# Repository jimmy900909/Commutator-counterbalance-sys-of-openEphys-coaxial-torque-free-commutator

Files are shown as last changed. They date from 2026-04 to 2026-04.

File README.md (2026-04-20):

This is a wireless counterbalance system that can adjust the length of the cable automatically for OpenEphys commutator while conducting freely moving animal experiment

#closed-loop Automatic Counterbalance animal experiment system

#tension-free and biting-prevention for cable in the freely moving animal experiment

The toggling and dragging can seriously cause the artifacts to signal when doing a cable-connected behavior experiment on an awake and freely-moving animal. The automatic rotation commutator is widely used in labs and commercialized, however, to adjust the length of the cable is always depends on manual holding or passive counterbalance sys. As the hanged part would be bited by animal and the tension can constraint the movement, a active counterbalance system is needed for such animal experiment.

This system consist of two part, openEphys(OE) commutator for torque-free compensation, and conterbalance system for tension control. 

Rotation commutator recieve the orientation data of the markers(rigid body) from Motive and send it to the commutator through Natnet SDK(https://optitrack.com/software/natnet-sdk)
The python code ui.py send the command that rotate the same degree as the target does to the commutator.

The counterbalance system detect the tension of the thread connected to the data acquisition cable, retract or release the thread to control the tension in a threshold.  

Following is the Assembly instructions of the mechanical structure. The CAD files are under counterbalance/mechanical design 


User guide
1.connect the OE commutator to the PC through the serial port(USB)
2.Open motive, select the reigid body and enable streaming
3.Run ui.py in the under the Natnet python client
4.Pause the rotation compensation first 
5.Set up the the counterbalance system by plug in the power, at the set time leave the thread from the loadcell to start from 0 weight.
6.start the rotation commutator

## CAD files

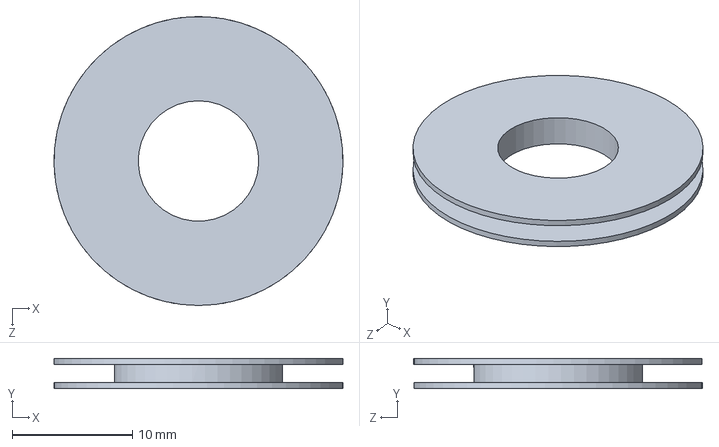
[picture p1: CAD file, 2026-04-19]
counterbalance/Mechanical design/pulley_fixed.SLDPRT
24.0 x 2.50 x 24.0 mm

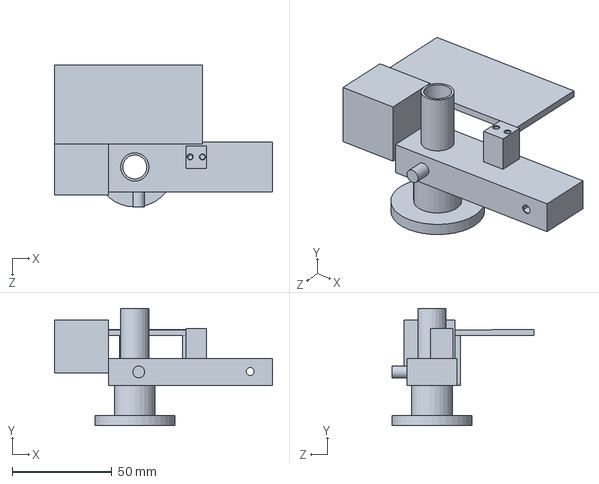
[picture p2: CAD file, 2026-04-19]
counterbalance/Mechanical design/Holder_OE.SLDPRT
109.1 x 58.7 x 71.0 mm

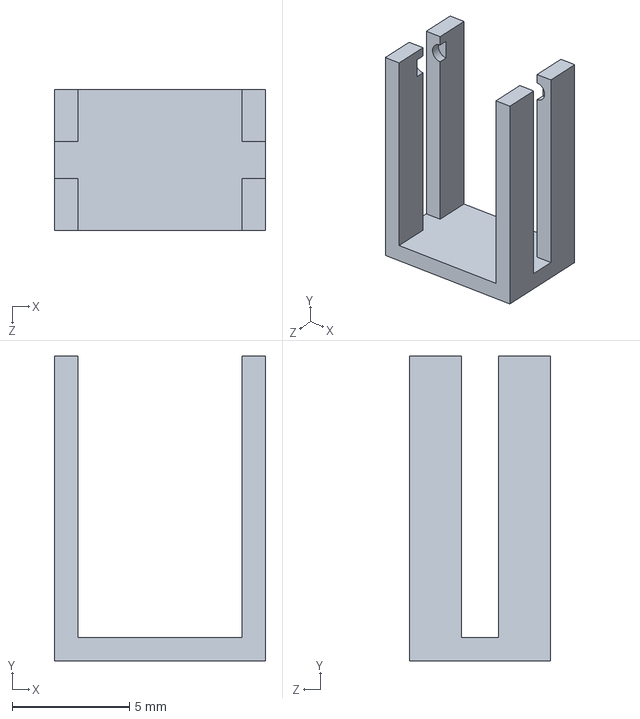
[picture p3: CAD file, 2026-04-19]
counterbalance/Mechanical design/loadcell_holder.SLDPRT
9.00 x 13.0 x 6.00 mm

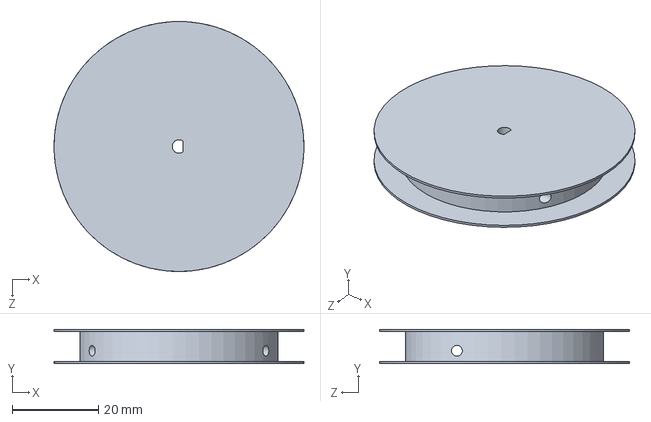
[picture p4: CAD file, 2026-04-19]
counterbalance/Mechanical design/pulley_motor.SLDPRT
58.0 x 8.00 x 58.0 mm

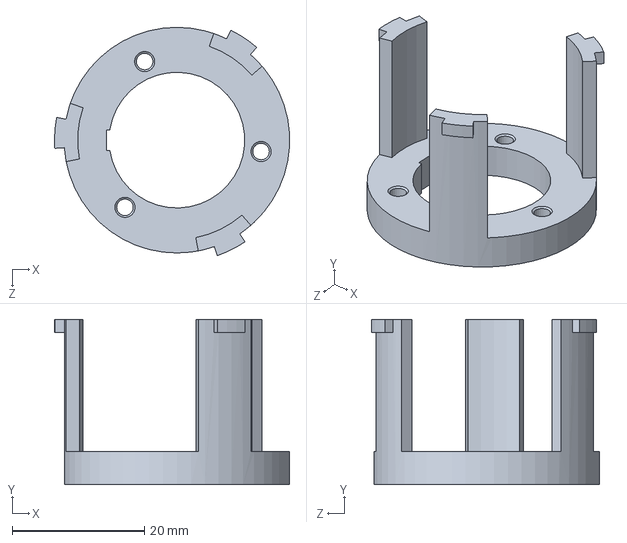
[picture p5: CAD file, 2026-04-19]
counterbalance/Mechanical design/adaptor_OE.SLDPRT
35.5 x 25.0 x 34.5 mm

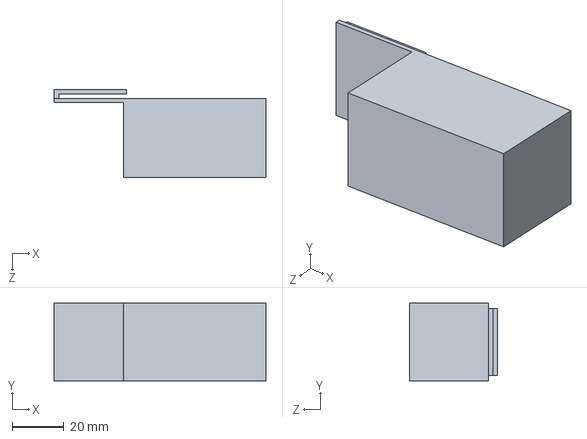
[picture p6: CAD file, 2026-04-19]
counterbalance/Mechanical design/powerbank_holder.SLDPRT
82.0 x 30.0 x 34.0 mm

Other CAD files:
counterbalance/Mechanical design/adaptor_OE.STL
counterbalance/Mechanical design/powerbank_holder.STL
counterbalance/Mechanical design/pulley_fixed.STL
counterbalance/Mechanical design/pulley_motor.STL

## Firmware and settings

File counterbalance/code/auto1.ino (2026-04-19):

#include "HX711.h"
// ---------------- Pins ----------------
// HX711
#define DOUT 4  
#define CLK  5  

// DRV8833(MOTOR driver)
#define AIN1 6
#define AIN2 9
// Encoder pins
#define ENCODER_A 2
#define ENCODER_B 3

// ---------------- HX711 ----------------
HX711 scale;
float calibration_factor = 7180;  // g
const float HX_RATE_HZ = 80.0f;   // sampling rate after soldering modication
unsigned long last_hx_ms = 0;
bool hx_updated = false;
bool have_prev_T = false;

// ---------------- Encoder → v_line ----------------
const float COUNTS_PER_METER = 11357.0f;
volatile long encoderCount = 0;
long lastCount = 0;
unsigned long lastVtMs = 0;
float v_line = 0.0f;         
float leash_len_m = 0.0f;

// ---------------- Motor / PWM ----------------
const int remotorSpeed = 65;   // retract PWM (upper bound)
int pwm_state = 0;
const int PWM_STEP_OUT = 80;   
const int PWM_STEP_IN  = 30;   
// retracting PWM
const int   BASE_RETRACT_PWM     = 35;     
const int   MAX_RETRACT_PWM      = 60;     
const int   MIN_RETRACT_PWM      = 40;     
const float KP_RETRACT_PWM_PER_G = 3.0f;   

// loosening PWM
const int   BASE_PAYOUT_PWM   = 50;
const int   MAX_PAYOUT_PWM    = 110; //upperlimit of payout
const float KP_PWM_PER_G      = 4.0f;

// ---------------- Burst（instantpayout for strong drag） ----------------
const int BURST_PWM = 100;                     
const unsigned long BURST_MS = 50;            
unsigned long burst_until_ms = 0;

// ---------------- Landing impact give-way ----------------
const float IMPACT_DTDT_GPS = 90.0f;            
const float IMPACT_NEAR_UPPER_G = 0.8f;         
const unsigned long IMPACT_COAST_MS = 120;      
const int IMPACT_PAYOUT_PWM = 70;               
unsigned long impact_until_ms = 0;              

// No instanst retracting after burst
const unsigned long POST_BURST_NO_RETRACT_MS = 600;     
unsigned long no_retract_until_ms = 0;

// ---------------- Smoothen tension for EMA filter----------------
float T_fast_g = 0.0f;                
float T_slow_g = 0.0f;                
const float T_ALPHA_FAST = 0.5f;      
const float T_ALPHA_SLOW = 0.3f;

// ---------------- threshold ----------------
float lower_limit = 22.3f;
float upper_limit = 37.5f;

float V_OUT_MIN = 0.004f;             
float T_MARGIN_G = 0.7f;
unsigned long ALLOW_PAYOUT_CONFIRM_MS = 5;  
bool allow_payout_latch = false;
unsigned long allow_payout_since_ms = 0;

// 鎖軸快速通道
const float V_EPS_LOCKED   = 0.003f;
const float T_LOCK_MARGING = 3.0f;
const float DTDT_LOCK_GPS  = 55.0f;
const unsigned long LOCK_CONFIRM_MS = 12;
bool locked_latch = false;
unsigned long locked_since_ms = 0;

// ---- dT/dt ----
float dTdt_raw = 0.0f;
float dTdt_gps = 0.0f;
float T_prev_for_dt = 0.0f;
const float DTDTA = 0.25f;

// Active-Coast when the tension near the upper limit
const int ASSIST_PWM = 80;               

// ---------------- Anti-chatter / Grace ----------------
bool inRetract = false;
unsigned long retract_start_ms;
long          retract_start_cnt;

const unsigned long MIN_RETRACT_MS  = 50;
const long          MIN_RETRACT_CNT = 10;

const unsigned long LOOSEN_GRACE_MS = 900;
unsigned long loosen_grace_until_ms = 0;

const float LOWER_HYST_G = 0.8f;

// ---------------- Loop time ----------------
const unsigned long LOOP_MS = 1;
unsigned long last_loop_ms = 0;

// ---------------- helpers ----------------
inline void motorCoast() {
  digitalWrite(AIN1, LOW);
  digitalWrite(AIN2, LOW);
}

void driveMotor(int pwmSigned) {
  if (pwmSigned == 0) { motorCoast(); return; }
  if (pwmSigned > 0) {           
    int pwm = constrain(pwmSigned, 0, 255);
    digitalWrite(AIN1, LOW);
    analogWrite(AIN2, pwm);
  } else {                       
    int pwm = constrain(-pwmSigned, 0, 255);
    analogWrite(AIN1, pwm);
    digitalWrite(AIN2, LOW);
  }
}

int slewPWM(int target) {
  if (target == pwm_state) return pwm_state;
  if ((target > 0 && pwm_state >= 0) || (target < 0 && pwm_state <= 0)) {
    int step = (target > 0) ? PWM_STEP_IN : PWM_STEP_OUT;
    if (target > pwm_state) pwm_state = min(pwm_state + step, target);
    else                    pwm_state = max(pwm_state - step, target);
  } else {
    int step = (pwm_state > 0) ? PWM_STEP_IN : PWM_STEP_OUT;
    if (pwm_state > 0) pwm_state = max(0, pwm_state - step);
    else               pwm_state = min(0, pwm_state + step);
  }
  return pwm_state;
}

int map_constrain_float(float x, float in_min, float in_max, int out_min, int out_max) {
  if (in_max - in_min == 0) return out_min;
  float t = (x - in_min) / (in_max - in_min);
  if (t < 0) t = 0; if (t > 1) t = 1;
  float y = out_min + t * (out_max - out_min);
  return (int)y;
}

int applyDeadzone(int pwmSigned) {
  const int DEADZONE = 70;   
  if (pwmSigned == 0) return 0;
  if (pwmSigned > 0) {
    return max(pwmSigned, DEADZONE);
  } else {
    return min(pwmSigned, -DEADZONE);
  }
}

// ---------------- setup ----------------
void setup() {
  Serial.begin(9600);
  delay(300);

  scale.begin(DOUT, CLK);
  delay(1500);
  if (!scale.is_ready()) { Serial.println("HX711 not found."); while (1); }
  scale.set_scale(calibration_factor);
  scale.tare();

  pinMode(AIN1, OUTPUT);
  pinMode(AIN2, OUTPUT);
  motorCoast();

  pinMode(ENCODER_A, INPUT_PULLUP);
  pinMode(ENCODER_B, INPUT_PULLUP);
  attachInterrupt(digitalPinToInterrupt(ENCODER_A), encoderISR, CHANGE);

  lastVtMs = millis();
  last_loop_ms = millis();
  last_hx_ms = millis();
  T_prev_for_dt = 0.0f;

  Serial.println("Ready ver5.instant-payout (no SD log).");
}

// ---------------- loop ----------------
void loop() {
  if (millis() - last_loop_ms < LOOP_MS) return;
  last_loop_ms = millis();

  // ---- 張力 ----
  hx_updated = false;
  float raw = 0.0f;
  if (scale.is_ready()) {
    raw = scale.get_units(1);
    T_fast_g = T_fast_g + T_ALPHA_FAST * (raw - T_fast_g);
    T_slow_g = T_slow_g + T_ALPHA_SLOW * (raw - T_slow_g);
    hx_updated = true;
  }
  float T_fast = T_fast_g;
  float T_slow = T_slow_g;

  unsigned long now = millis();
  unsigned long dt_ms = now - lastVtMs; if (dt_ms == 0) dt_ms = 1;
  lastVtMs = now;

  long cnt; noInterrupts(); cnt = encoderCount; interrupts();
  long dcount = cnt - lastCount; lastCount = cnt;

  float dt = dt_ms * 1e-3f;
  v_line = (COUNTS_PER_METER > 1e-6f) ? ((float)dcount / COUNTS_PER_METER) / dt : 0.0f;
  leash_len_m += v_line * dt;

  if (hx_updated) {
    float dtT_s = max(0.001f, (now - last_hx_ms) * 1e-3f);
    if (!have_prev_T) { dTdt_raw = 0.0f; have_prev_T = true; }
    else               dTdt_raw = (T_fast - T_prev_for_dt) / dtT_s;
    T_prev_for_dt = T_fast;
    last_hx_ms = now;
  }
  dTdt_gps = DTDTA * dTdt_raw + (1.0f - DTDTA) * dTdt_gps;

  // ---- instant payout decision ----
  bool sudden_pull = ((raw > upper_limit + 15.0f) || (T_fast > upper_limit + 15.0f)) && (dTdt_gps > 70.0f);
  bool not_retracting = (v_line <= 0.0f);
  bool instant_payout = sudden_pull && not_retracting;

  if (instant_payout) {
    unsigned long new_until = now + BURST_MS;
    if (new_until > burst_until_ms) burst_until_ms = new_until;
    loosen_grace_until_ms = max(loosen_grace_until_ms, now + LOOSEN_GRACE_MS);
    no_retract_until_ms   = max(no_retract_until_ms,   now + POST_BURST_NO_RETRACT_MS);
    inRetract = false;
    Serial.println("00000");
    allow_payout_latch = true;
    allow_payout_since_ms = now;
  }

  if (now < burst_until_ms) {
    int steppedPWM = slewPWM(-BURST_PWM);
    steppedPWM = applyDeadzone(steppedPWM);
    driveMotor(steppedPWM);
    return;
  }

  bool impact_detect = inRetract && ((dTdt_gps > IMPACT_DTDT_GPS) || (T_fast > upper_limit - IMPACT_NEAR_UPPER_G));
  if (impact_detect) {
    unsigned long new_until = now + IMPACT_COAST_MS;
    if (new_until > impact_until_ms) impact_until_ms = new_until;
  }
  if (now < impact_until_ms) {
    int targetPWM = 0;
    if (T_fast > upper_limit - 0.3f) {
      targetPWM = -IMPACT_PAYOUT_PWM; 
    }
    int steppedPWM = slewPWM(targetPWM);
    steppedPWM = applyDeadzone(steppedPWM);
    driveMotor(steppedPWM);
    inRetract = false;
    return;
  }

  bool line_out = (v_line < -V_OUT_MIN);
  bool high_T   = (T_fast > (upper_limit + T_MARGIN_G));
  if (high_T) {
    if (!allow_payout_latch) { allow_payout_latch = true; allow_payout_since_ms = now; }
  } else {
    allow_payout_latch = false;
  }
  bool allow_payout_dir = allow_payout_latch && (now - allow_payout_since_ms >= ALLOW_PAYOUT_CONFIRM_MS);

  bool spool_static = (fabs(v_line) < 0.003f);
  bool locked_trig  = spool_static && (T_fast > upper_limit + T_LOCK_MARGING) && (dTdt_gps > DTDT_LOCK_GPS);
  if (locked_trig) {
    if (!locked_latch) { locked_latch = true; locked_since_ms = now; }
  } else {
    locked_latch = false;
  }
  bool allow_payout_locked = locked_latch && (now - locked_since_ms >= LOCK_CONFIRM_MS);
  bool allow_payout = allow_payout_dir || allow_payout_locked;

  int targetPWM = 0;
  if (T_fast > upper_limit) {
    if (allow_payout) {
      float over_g = T_fast - upper_limit;
      int pwm = (int)(BASE_PAYOUT_PWM + KP_PWM_PER_G * over_g);
      pwm = constrain(pwm, BASE_PAYOUT_PWM, MAX_PAYOUT_PWM);
      targetPWM = -pwm;
      loosen_grace_until_ms = now + LOOSEN_GRACE_MS;
      no_retract_until_ms   = max(no_retract_until_ms, now + POST_BURST_NO_RETRACT_MS);
      inRetract = false;
    } else {
      targetPWM = 0;
    }
  } else if (T_slow < (lower_limit - LOWER_HYST_G)
             && now >= loosen_grace_until_ms
             && now >= no_retract_until_ms) {
    if (!inRetract) { inRetract = true; retract_start_ms = now; retract_start_cnt = cnt; }
    float under_g = (lower_limit - T_slow);
    int pwm = (int)(BASE_RETRACT_PWM + KP_RETRACT_PWM_PER_G * under_g);
    pwm = constrain(pwm, MIN_RETRACT_PWM, MAX_RETRACT_PWM);
    targetPWM = +pwm;
  } else if (T_fast < lower_limit) {
    targetPWM = 0;
  } else {
    if (inRetract) {
      if (T_fast > upper_limit - 0.8f) { targetPWM = 0; inRetract = false; }
      else {
        bool time_ok = (now - retract_start_ms) >= MIN_RETRACT_MS;
        bool cnt_ok  = (labs(cnt - retract_start_cnt) >= MIN_RETRACT_CNT);
        bool window_ok = (now >= loosen_grace_until_ms) && (now >= no_retract_until_ms);
        if (time_ok && cnt_ok && window_ok) { targetPWM = 0; inRetract = false; }
        else {
          int cap = map_constrain_float(T_fast, lower_limit - 1.0f, upper_limit - 0.5f, remotorSpeed, 10);
          cap = constrain(cap, 10, remotorSpeed);
          targetPWM = +cap;
        }
        if (!window_ok) { targetPWM = 0; inRetract = false; }
      }
    } else {
      targetPWM = 0;
    }
  }

  bool nearly_upper = (T_fast >= (upper_limit - 0.3f));
  if (targetPWM == 0 && nearly_upper && spool_static) {
    targetPWM = -ASSIST_PWM;
  }

  if (now < loosen_grace_until_ms || now < no_retract_until_ms) {
    if (targetPWM > 0) { targetPWM = 0; }
  }

  int steppedPWM = slewPWM(targetPWM);
  steppedPWM = applyDeadzone(steppedPWM);
  driveMotor(steppedPWM);

  if ((millis() % 100) < LOOP_MS) {
    Serial.print("T_fast(g)="); Serial.print(T_fast, 2);
    Serial.print("  T_slow(g)="); Serial.print(T_slow, 2);
    Serial.print("  v_line(m/s)="); Serial.print(v_line, 3);
    Serial.print("  PWM="); Serial.print(steppedPWM);
    Serial.println();
  }
}

// ---------------- ISR ----------------
void encoderISR() {
  int a = digitalRead(ENCODER_A);
  int b = digitalRead(ENCODER_B);
  if (a == b) encoderCount++;
  else        encoderCount--;
}

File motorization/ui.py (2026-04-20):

import sys
import time
import json
import serial
import pyqtgraph.opengl as gl
from PyQt5.QtWidgets import QApplication, QMainWindow, QVBoxLayout, QWidget, QLabel, QPushButton, QMessageBox
from PyQt5.QtCore import QTimer
from threading import Thread, Lock
from NatNetClient import NatNetClient
import numpy as np


class RealTimeDataAnalyzer3D(QMainWindow):
    def __init__(self):
        super().__init__()

        # -------------------------------
        # UI Setup
        # -------------------------------
        self.setWindowTitle("Real-Time Rigid Body 3D Position and Rotation")
        self.setGeometry(100, 100, 1200, 800)

        # Pause state for commutator control
        self.is_paused = False

        # -------------------------------
        # Serial Communication Config
        # -------------------------------
        self.SERIAL_PORT = "COM6"
        self.BAUDRATE = 9600
        self.DEGREES_PER_TURN = 360

        try:
            self.ser = serial.Serial(self.SERIAL_PORT, self.BAUDRATE, timeout=1)
            time.sleep(2)
        except serial.SerialException as e:
            self.ser = None
            QMessageBox.critical(self, "Serial Error", f"{e}")

        # -------------------------------
        # Main Layout
        # -------------------------------
        self.central_widget = QWidget()
        self.setCentralWidget(self.central_widget)
        self.layout = QVBoxLayout()
        self.central_widget.setLayout(self.layout)

        # -------------------------------
        # 3D Visualization Setup
        # -------------------------------
        self.plot_widget = gl.GLViewWidget()
        self.plot_widget.setFixedSize(800, 600)
        self.layout.addWidget(self.plot_widget)
        self.plot_widget.setCameraPosition(distance=10)

        grid = gl.GLGridItem()
        grid.scale(0.1, 0.1, 0.1)
        self.plot_widget.addItem(grid)

        self.traj_line = gl.GLLinePlotItem()
        self.plot_widget.addItem(self.traj_line)

        # -------------------------------
        # UI Labels
        # -------------------------------
        self.position_label = QLabel("Position: X=0.00, Y=0.00, Z=0.00")
        self.layout.addWidget(self.position_label)

        self.rotation_label = QLabel("Accumulated Rotation: 0.00 deg")
        self.layout.addWidget(self.rotation_label)

        self.status_label = QLabel("Status: Running")
        self.layout.addWidget(self.status_label)

        self.pause_button = QPushButton("Pause Commutator")
        self.pause_button.clicked.connect(self.toggle_pause_resume)
        self.layout.addWidget(self.pause_button)

        # -------------------------------
        # Data Buffers
        # -------------------------------
        self.positions = []
        self.data_lock = Lock()

        # Quaternion tracking
        self.q_prev = None

        # Accumulated rotation (core logic from second code)
        self.accum_angle = 0.0

        # Control parameters
        self.ANGLE_THRESHOLD = 90.0
        self.MAX_VALID_DELTA = 40.0
        self.GAIN = 1.0

        # -------------------------------
        # Timer for UI updates
        # -------------------------------
        self.timer = QTimer()
        self.timer.timeout.connect(self.update_chart)
        self.timer.start(100)

        # -------------------------------
        # NatNet streaming thread
        # -------------------------------
        self.streaming_client = NatNetClient()
        self.streaming_client.rigid_body_listener = self.receive_rigid_body_frame
        self.client_thread = Thread(target=self.streaming_client.run)
        self.client_thread.start()

    # -------------------------------
    # Quaternion math utilities
    # -------------------------------
    def quat_mul(self, a, b):
        """Multiply two quaternions"""
        w1, x1, y1, z1 = a
        w2, x2, y2, z2 = b
        return np.array([
            w1*w2 - x1*x2 - y1*y2 - z1*z2,
            w1*x2 + x1*w2 + y1*z2 - z1*y2,
            w1*y2 - x1*z2 + y1*w2 + z1*x2,
            w1*z2 + x1*y2 - y1*x2 + z1*w2
        ])

    def quat_conj(self, q):
        """Compute quaternion conjugate"""
        w, x, y, z = q
        return np.array([w, -x, -y, -z])

    def ensure_continuity(self, q, q_prev):
        """Avoid quaternion sign flip (q and -q represent same rotation)"""
        if q_prev is not None and np.dot(q, q_prev) < 0:
            q = -q
        return q

    def delta_yaw(self, q_now, q_prev):
        """Compute incremental rotation projected onto Y-axis (yaw-like)"""
        dq = self.quat_mul(q_now, self.quat_conj(q_prev))

        w, x, y, z = dq
        v = np.array([x, y, z])
        norm_v = np.linalg.norm(v)

        if norm_v < 1e-12:
            return 0.0

        axis = v / norm_v
        angle = 2.0 * np.degrees(np.arctan2(norm_v, w))

        # Project rotation axis onto Y axis
        up = np.array([0, 1, 0])
        sign = np.sign(np.dot(axis, up))

        return angle * (1.0 if sign >= 0 else -1.0)

    # -------------------------------
    # Send JSON command to commutator
    # -------------------------------
    def send_rotation_command(self, angle):
        """Send rotation command in JSON format"""
        if self.ser is None or not self.ser.is_open:
            return

        turns = angle / self.DEGREES_PER_TURN

        json_state = {
            "enable": True,
            "led": True,
            "turn": turns,
            "print": True
        }

        try:
            self.ser.write((json.dumps(json_state) + "\n").encode("utf-8"))
        except Exception as e:
            print(f"Serial Error: {e}")

    # -------------------------------
    # Pause / Resume control
    # -------------------------------
    def toggle_pause_resume(self):
        """Toggle commutator state"""
        self.is_paused = not self.is_paused

        if self.is_paused:
            self.status_label.setText("Status: Paused")
            self.pause_button.setText("Resume")
        else:
            self.status_label.setText("Status: Running")
            self.pause_button.setText("Pause")

    # -------------------------------
    # NatNet callback (core logic)
    # -------------------------------
    def receive_rigid_body_frame(self, rigid_body_id, position, orientation):
        """Handle incoming rigid body data"""

        if self.is_paused:
            return

        # Convert NatNet quaternion (x,y,z,w) → (w,x,y,z)
        ox, oy, oz, ow = orientation
        q = np.array([ow, ox, oy, oz])
        q = q / np.linalg.norm(q)

        # Ensure continuity to avoid sudden flips
        q = self.ensure_continuity(q, self.q_prev)

        if self.q_prev is None:
            self.q_prev = q
            return

        # Compute incremental yaw rotation
        delta = self.delta_yaw(q, self.q_prev) * self.GAIN
        self.q_prev = q

        # Reject abnormal spikes
        if abs(delta) > self.MAX_VALID_DELTA:
            return
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
